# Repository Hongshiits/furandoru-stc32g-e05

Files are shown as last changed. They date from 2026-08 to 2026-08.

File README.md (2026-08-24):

# Furandoru STC32G E05

基于逐飞科技 `STC32G144K246 100Pin` 开源库和 Coreboard `E05_pwm_demo` 整理的 Furandoru 循迹车工程。仓库包含 E05 实际固件与修改后的 Coreboard 库、PC 端仿真、电路硬件安全导出，以及 SolidWorks/STEP/STL/DXF 等机械资料。

## 功能概览

- 五路 ADC 循迹信号采集与归一化（`LV / LH / MD / RH / RV`）
- 左右轮编码器反馈、PWM 电机驱动和增量式速度 PID
- IMU660RA 默认支持，可通过源码宏切换 IMU660RB
- 直线、弯道、十字和环岛等状态处理
- 串口 Horn Shell 参数调试，以及仍处于实验状态的 EEPROM 参数读写
- 双电机与虚拟导线循迹的纯 Python 仿真
- 立创 EDA/Altium 工程、BOM/Gerber、二维板框与按修改时间归档的安全导出
- SolidWorks 原生装配、可制造 STL/DXF/3MF 及带 GPL-3.0 许可证的轻量化车模快照

> 这是竞赛/实验固件快照。首次上车前请核对引脚、电机方向、传感器量程和 PID 参数，并先架空车轮测试。

> 本仓库不是逐飞科技官方仓库，当前按维护者要求保持公开。部分 Keil/STC、预编译 `.LIB`、硬件和机械资产随源目录未附独立再分发条款；公开可见不等于统一获得 GPL 授权。详见 [`THIRD_PARTY_NOTICES.md`](THIRD_PARTY_NOTICES.md)。

## 目录

```text
firmware/
├── E05_pwm_demo/
│   ├── code/       # Keil 工程保留的用户代码目录
│   ├── mdk/        # Keil C251 工程
│   └── user/       # Furandoru 应用代码
└── libraries/      # E05 工程引用的逐飞 Coreboard 库（含本项目修改）
tools/
└── e05_pwm_virtual_env/  # PC 端控制算法与导线循迹仿真
hardware/
├── projects/             # EDA 安全导出与 MUX_EMF 源工程
├── history/              # 按源修改时间整理的 EDA 历史版本
├── manufacturing/        # BOM、Gerber 与投板资料
├── libraries/            # 已审计的立创 EDA 元件库
└── mechanical-interfaces/ # 二维板框与接口图
mechanical/
├── solidworks/           # 原生模型、装配与制造格式
└── third-party/          # 保留上游许可证的第三方快照
scripts/
├── verify_project.py     # 固件工程相对路径检查
└── verify_assets.py      # 资产哈希、禁入格式与秘密标记检查
docs/
├── UPSTREAM_AND_CHANGES.md
├── ASSET_IMPORT_SUMMARY.md
└── ASSET_IMPORT_MAP.csv  # 原路径、时间、哈希、重命名/去重/排除追踪
```

## 克隆与 Git LFS

CAD/EDA/3D 二进制使用 Git LFS。完整克隆前先安装 Git LFS：

```powershell
git lfs install
git clone https://github.com/Hongshiits/furandoru-stc32g-e05.git
cd furandoru-stc32g-e05
git lfs pull
```

直接下载 GitHub 自动生成的源码 ZIP 时，LFS 文件可能只是指针；需要完整工程时应使用上述克隆方式。

## 构建固件

1. 安装支持 C251 的 Keil MDK 工具链和对应设备支持包。
2. 打开 [`firmware/E05_pwm_demo/mdk/seekfree.uvproj`](firmware/E05_pwm_demo/mdk/seekfree.uvproj)。
3. 确认目标设备为 `AI8052U-32Bit Series`，然后执行 Build。
4. 默认输出目录为 `firmware/E05_pwm_demo/mdk/out_file/`，输出名为 `SEEKFREE`。

工程使用相对路径 `../../libraries`，从仓库克隆后无需手工重连库文件。当前整理环境没有安装 Keil/C251，因此发布前完成的是工程引用完整性检查和 PC 仿真检查，而不是目标固件的实际编译。

## 关键配置入口

- ADC 通道：`firmware/E05_pwm_demo/user/adc.h`
- PWM、电机限幅与死区：`firmware/E05_pwm_demo/user/pwm.h`
- 编码器接口：`firmware/E05_pwm_demo/user/encoder.h`
- IMU 型号切换：`firmware/E05_pwm_demo/user/imu.h`
- 控制器初始参数：`firmware/E05_pwm_demo/user/algorithm.c`
- 赛道状态与阈值：`firmware/E05_pwm_demo/user/fsm_leg.c`

`user/ekf.*`、`user/gyro.*` 和 `user/matrix.*` 是当前保留的实验模块，尚未列入 `seekfree.uvproj` 的编译文件组。

当前源码中的主要默认连接如下：

| 功能 | 默认接口 |
| --- | --- |
| 五路循迹 ADC | `P06 / P03 / P02 / P01 / P00` |
| 电池电压 ADC | `P10` |
| 三路 PWM | `P74 / P24 / P70` |
| 电机方向 | `P35 / P36 / P37` |
| 左右编码器 | `P60/P62`、`P40/P42` |
| 调试串口 | UART5，`P05/P04`，115200 baud |
| 默认 IMU | IMU660RA；在 `imu.h` 中启用宏可切换 IMU660RB |
| 系统时钟 | 96 MHz |

EEPROM 相关源码仍带有“存在问题”的开发注释，应视为实验功能，在真机验证前不要依赖其保存关键参数。

## PC 仿真

工具仅依赖 Python 标准库；图形界面还需要 Python 自带的 Tk 支持。

```powershell
python tools/e05_pwm_virtual_env/e05_pwm_virtual_env.py --mode track --duration 8 --dt 0.01 --aim-speed 60 --direction 1
python tools/e05_pwm_virtual_env/e05_wire_graph_app.py --headless-steps 300
```

运行图形界面：

```powershell
python tools/e05_pwm_virtual_env/e05_wire_graph_app.py
```

## 发布前自检

```powershell
python scripts/verify_project.py
python scripts/verify_assets.py
```

第一个脚本验证 Keil 工程中的源文件和包含目录；第二个脚本核对 320 条资产导入记录、发布文件 SHA-256、禁入格式和常见秘密标记。

## 硬件与 3D 资产规则

硬件说明见 [`hardware/README.md`](hardware/README.md)，机械依赖与装配注意事项见 [`mechanical/README.md`](mechanical/README.md)。同名不同内容的独立文件使用 `__YYYYMMDD-HHMMSS` 后缀，字节相同的副本通常只保留一份；SolidWorks 装配体和依赖零件则保持原名同目录，避免破坏引用。唯一的跨上下文重复是 N30 主板支架 DXF：硬件接口目录保留一份，同时不破坏带许可证第三方快照的完整目录。

公开审计发现原始 `.eprj/.eprj2` 是带本地用户凭据的 SQLite 数据库，因此没有发布；可用工程以 `.epro/.epro2` 安全导出为准。147.9 MB 扫描参考图、构建日志、Keil 许可证码、调试/锁文件和来源未确认的商品图也已排除。完整原因和原始时间均在 [`docs/ASSET_IMPORT_MAP.csv`](docs/ASSET_IMPORT_MAP.csv)。

## 来源与许可证

本项目基于逐飞科技 STC32G144K 开源库，原文件版权声明均予以保留。整理基准、工作区修改范围和删减规则见 [`docs/UPSTREAM_AND_CHANGES.md`](docs/UPSTREAM_AND_CHANGES.md)。部分上游 C/汇编文件保留原始 GBK 或混合编码；整理过程没有批量转码，以免改变编译输入。

逐飞固件来源文件继续遵循其文件头声明的 GPLv3 或后续版本，项目自有修改也拟按 GPL-3.0-or-later 发布。根目录 [LICENSE](LICENSE) 收录 GPLv3 全文；`mechanical/third-party/lightweight-car-chassis/` 另保留其上游许可证。Keil、STC、预编译库及许可未明确的硬件/机械资产仍分别遵循其权利人的条款，仓库公开状态不改变这些第三方权利。

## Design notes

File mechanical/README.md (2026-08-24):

# 3D 模型与机械资料

本目录整理 SolidWorks 原生文件、制造/交换格式和一个带明确 GPL-3.0 许可证的逐飞轻量化车模快照。原始路径、修改时间、去重与排除记录见 [`docs/ASSET_IMPORT_MAP.csv`](../docs/ASSET_IMPORT_MAP.csv)。

## 目录

```text
mechanical/
├── solidworks/
│   ├── n30-zfcar/          # 原生装配/零件与 STL、DXF、3MF 导出
│   ├── custom-0429-130/    # Furandoru 自制零件、工程图与导出
│   └── fan-motor-mount/    # 负压风扇及电机支架
└── third-party/
    └── lightweight-car-chassis/ # SeekFree 项目及原 LICENSE/README
```

## SolidWorks 依赖保护

`solidworks/n30-zfcar/native/` 中所有 `.SLDASM` 和 `.SLDPRT` 保持原始文件名并置于同一目录，避免直接改名破坏装配引用：

| 装配体 | 依赖零件 |
| --- | --- |
| `Assem1.SLDASM` | `电磁支架固定2.SLDPRT`、`Mirror电磁支架固定2.SLDPRT` |
| `Assem2.SLDASM` | `电磁支架固定2.SLDPRT`、`Mirror电磁支架固定21.SLDPRT` |
| `Assem3.SLDASM` | `电磁支架固定2.SLDPRT`、`Mirror电磁支架固定2.SLDPRT` |

两个镜像零件还带有对原零件或装配上下文的外部引用。后续若要改名，请使用 SolidWorks **Pack and Go** 或“替换引用”，不要在资源管理器中直接改名。

`custom-0429-130/native/` 内的 `furan-fan-frame.SLDDRW`、`一体板板框_兼容逐飞_V1.1.SLDDRW` 和 `furan_top_support_rightMirror.SLDPRT` 保存过失效的旧绝对路径；其目标零件仍与它们同目录，SolidWorks 通常可通过同目录搜索恢复。首次打开后应人工确认所有引用，再另存或 Pack and Go。

## 版本与删减

- STL 和独立零件的同名不同内容版本使用 `__YYYYMMDD-HHMMSS` 后缀；字节完全相同的副本只保留一份。
- 原生装配依赖文件不参与文件系统重命名。
- 已排除 5 个 `~$` 锁文件、12 个 `.bak`、两个与解压内容完全相同的 ZIP、5 张许可未确认的商品参考图，以及一份二进制属性嵌入本地用户名且无法无损清理的 DWG。
- 发布的 DXF 已清除 `$LASTSAVEDBY` 和绝对源文件路径字段，几何实体保持不变。
- 已排除 `Scan2026-03-13_234830.png`（147,900,842 bytes，9637×13747）：它不是 3D 工程文件且超过 GitHub 普通 Git 的 100 MiB 单文件限制。

## 来源与许可

`third-party/lightweight-car-chassis/` 对应 SeekFree 的 Lightweight Car Chassis 项目，完整保留上游 `LICENSE`、中英文 README 和目录结构；其中后续加入的本地派生文件也按 GPL-3.0 兼容方式发布。

`n30-zfcar`、`fan-motor-mount` 以及 `custom-0429-130` 中带“逐飞”名称的部分在源目录中没有随附独立许可证，不能仅凭另一个目录含 GPL 文件就推定授权。它们按维护者的公开发布要求隔离整理，但公开可见本身不授予额外权利；复用或再分发前请核实来源和许可。详见 [`THIRD_PARTY_NOTICES.md`](../THIRD_PARTY_NOTICES.md)。

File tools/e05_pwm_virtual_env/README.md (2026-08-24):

# E05 PWM Virtual Environment

This folder provides a PC-side simulation for `firmware/E05_pwm_demo`.

## What is simulated

- `pt_pwm_init()` channel configuration
- `Motor_act()` direction + PWM absolute duty behavior
- Incremental motor PID logic from `pid_leg.c`
- A lightweight virtual plant for left/right encoder speed and yaw

The simulator is for algorithm validation and tuning trend checks. It is not intended to replace real hardware calibration.

## Run

From repository root:

```powershell
python tools/e05_pwm_virtual_env/e05_pwm_virtual_env.py --mode track --duration 8 --dt 0.01 --aim-speed 60 --direction 1
```

Corner-like mode:

```powershell
python tools/e05_pwm_virtual_env/e05_pwm_virtual_env.py --mode corner --duration 8
```

## Output

- Console summary with average PWM and final speeds/yaw
- CSV trace file (default): `tools/e05_pwm_virtual_env/sim_trace.csv`

You can change CSV output path:

```powershell
python tools/e05_pwm_virtual_env/e05_pwm_virtual_env.py --csv tools/e05_pwm_virtual_env/my_trace.csv
```

## Main parameters

- `--mode`: `track` or `corner`
- `--duration`: total simulation time in seconds
- `--dt`: simulation step period in seconds
- `--aim-speed`: equivalent to firmware `aim_speed`
- `--direction`: 1 (counterclockwise) or 2 (clockwise)

## Graph Simulation Application (Wire Signal Following)

The file `tools/e05_pwm_virtual_env/e05_wire_graph_app.py` is a graphical app for the E05 car scenario:

- A curved virtual wire radiates signal into air
- The car captures signal strength through 5 virtual sensors (`LV/LH/MD/RH/RV`)
- Steering uses an `Error_Turn` style formula similar to `isr_leg.c`
- Live graphs show ADC strength, error/yaw rate, and left/right PWM

Run GUI:

```powershell
python tools/e05_pwm_virtual_env/e05_wire_graph_app.py
```

Run headless quick check:

```powershell
python tools/e05_pwm_virtual_env/e05_wire_graph_app.py --headless-steps 300
```

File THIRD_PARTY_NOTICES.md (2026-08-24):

# 第三方组件与公开仓库说明

本仓库当前为公开仓库。本文件记录整理时能从源文件直接确认的许可证，以及仍未在源目录中找到独立再分发条款的组件。公开可见不等于这些组件统一改授仓库根目录的 GPL，也不替代权利人的正式许可。

## 逐飞 STC32G144K 固件库

`firmware/libraries` 和 E05 示例的大部分源文件包含成都逐飞科技有限公司的版权声明，并声明按 GPLv3 或后续版本授权。仓库根目录 `LICENSE` 保留了源工作副本提供的 GPLv3 全文；原文件头不得删除。

源文件头提到的 `libraries/doc/GPL3_permission_statement.txt` 和 `libraries/LICENSE` 在被整理的源工作副本中并不存在，只有仓库根目录 `LICENSE`。这里记录该不一致，不伪造缺失的上游文件。

## SeekFree Lightweight Car Chassis

`mechanical/third-party/lightweight-car-chassis/` 对应 SeekFree 的 Lightweight Car Chassis 项目，保留了上游 `LICENSE`、`README.md`、`README.en.md` 和原目录结构。该快照随附 GNU GPL v3；本地新增或派生的 `电磁支架底座.*`、DWG/DXF/SLDDRW 等文件按兼容方式公开，并由导入清单记录原修改时间。

上游来源：<https://gitee.com/seekfree/Lightweight_Car_Chassis>

## Keil、STC 与预编译库

以下固件构建依赖随源工作副本没有附带可单独确认的再分发条款：

- `firmware/libraries/zf_common/START251.A51`（Keil 版权声明）
- `firmware/libraries/zf_common/stc32g144k246.h`
- `firmware/libraries/zf_common/ai_usb.h`
- `firmware/libraries/zf_components/stc32g_usb_lib/`
- `firmware/libraries/zf_device/zf_device_config.LIB`
- `firmware/libraries/zf_device/zf_device_mt9v03x_dma.LIB`

它们为保持当前 Keil/C251 工程完整性而保留。维护者将仓库设为公开并不构成对其授权状态的保证；下游应核实 Keil、STC 或对应权利人的许可，或在分发前以已安装工具链/许可明确实现替换。

## 电路硬件资料

`hardware/` 中的 EDA 导出、制造文件和机械接口来自项目工作目录。以下类别在源目录中没有找到独立许可证，不能推定均适用根目录 GPL：

- 部分参考板 PDF（原 Altium 库因嵌入绝对用户路径且许可未明而未发布）
- 芯片数据手册及厂商文档
- MiniFOC、MUX_EMF 参考设计/代码
- 其他带厂商或第三方来源标识的工程

文件名明确为“仿逐飞1比1”的工程因授权未确认而未发布。原始 `.eprj/.eprj2/.eprj_backup` 因嵌入本地用户凭据而全部排除；只发布已审计的 `.epro/.epro2` 导出。含 Keil `LIC` 的构建日志和聚合 ZIP 也未进入仓库。具体结果见 `docs/ASSET_IMPORT_MAP.csv`。

## 其他 SolidWorks 模型

下列目录的源工作副本没有随附独立许可证：

- `mechanical/solidworks/n30-zfcar/`
- `mechanical/solidworks/fan-motor-mount/`
- `mechanical/solidworks/custom-0429-130/` 中带“逐飞”名称的部分

它们按维护者要求隔离整理并保持工程依赖，但不能仅因 SeekFree 的另一个项目带 GPL 文件就推定获得相同授权。复用、修改或再分发前应确认原作者、来源和适用条款。电商商品图及来源未确认的参考图没有发布。

## 安全与隐私删减

公开导入明确排除了：本地 EDA 凭据数据库、Keil 许可证码、绝对用户构建路径、调试日志、构建产物、个人状态文件、SolidWorks/Office 锁文件和 Office 作者元数据；DXF 头中的绝对源路径也已清除。`scripts/verify_assets.py` 会检查导入清单、哈希、禁入格式和常见秘密标记。

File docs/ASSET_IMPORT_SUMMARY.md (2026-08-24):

# 硬件与机械资产导入摘要

本摘要由本地导入脚本根据源文件 SHA-256、原始修改时间和工程依赖规则生成。Git 本身不保存文件修改时间，完整追溯信息见 [`ASSET_IMPORT_MAP.csv`](ASSET_IMPORT_MAP.csv)。

## 结果

- 源文件：320 个，403,850,217 bytes
- 实际发布：188 个，70,524,253 bytes
- 字节级去重：27 个源路径
- 排除：105 个源文件
- 同名不同内容版本组：12 组

## 同名不同内容的版本化结果

| 统一名称 | 版本 | 发布路径 | 原修改时间 | SHA-256 前 12 位 |
| --- | ---: | --- | --- | --- |
| `AI8052U-64-furan-0203.zip` | 1/5 | `hardware/history/easyeda/AI8052U-64-furan-0203/AI8052U-64-furan-0203__20260207-164544.zip` | 2026-02-07T16:45:44+08:00 | `BDD78105EEAB` |
| `↳` | 2/5 | `hardware/history/easyeda/AI8052U-64-furan-0203/AI8052U-64-furan-0203__20260207-184545.zip` | 2026-02-07T18:45:45+08:00 | `3B76DF684E0E` |
| `↳` | 3/5 | `hardware/history/easyeda/AI8052U-64-furan-0203/AI8052U-64-furan-0203__20260208-191833.zip` | 2026-02-08T19:18:33+08:00 | `5D4A5C32AF92` |
| `↳` | 4/5 | `hardware/history/easyeda/AI8052U-64-furan-0203/AI8052U-64-furan-0203__20260208-201833.zip` | 2026-02-08T20:18:33+08:00 | `460EB6462E17` |
| `↳` | 5/5 | `hardware/history/easyeda/AI8052U-64-furan-0203/AI8052U-64-furan-0203__20260208-211836.zip` | 2026-02-08T21:18:36+08:00 | `695D77CDF1BD` |
| `AI8052U-64-furan-0209 (1).epro2` | 1/2 | `hardware/history/easyeda/AI8052U-64-furan-0209 (1)/AI8052U-64-furan-0209 (1)__20260508-173740.epro2` | 2026-05-08T17:37:40+08:00 | `57D7F42667CC` |
| `↳` | 2/2 | `hardware/history/easyeda/AI8052U-64-furan-0209 (1)/AI8052U-64-furan-0209 (1)__20260508-223744.epro2` | 2026-05-08T22:37:44+08:00 | `467EE6108F1A` |
| `AI8052U-64-furan-0322.epro2` | 1/6 | `hardware/history/easyeda/AI8052U-64-furan-0322/AI8052U-64-furan-0322__20260521-224928.epro2` | 2026-05-21T22:49:28+08:00 | `74D4713A2D7C` |
| `↳` | 2/6 | `hardware/history/easyeda/AI8052U-64-furan-0322/AI8052U-64-furan-0322__20260521-234932.epro2` | 2026-05-21T23:49:32+08:00 | `B19FD54C1875` |
| `↳` | 3/6 | `hardware/history/easyeda/AI8052U-64-furan-0322/AI8052U-64-furan-0322__20260522-004935.epro2` | 2026-05-22T00:49:35+08:00 | `5C9283C3F653` |
| `↳` | 4/6 | `hardware/history/easyeda/AI8052U-64-furan-0322/AI8052U-64-furan-0322__20260522-014930.epro2` | 2026-05-22T01:49:30+08:00 | `AA692DF5E637` |
| `↳` | 5/6 | `hardware/history/easyeda/AI8052U-64-furan-0322/AI8052U-64-furan-0322__20260522-034932.epro2` | 2026-05-22T03:49:32+08:00 | `93A4187882EE` |
| `↳` | 6/6 | `hardware/history/easyeda/AI8052U-64-furan-0322/AI8052U-64-furan-0322__20260526-033540.epro2` | 2026-05-26T03:35:40+08:00 | `D8914A096168` |
| `AI8052U-64-furan-0322.zip` | 1/4 | `hardware/history/easyeda/AI8052U-64-furan-0322/AI8052U-64-furan-0322__20260501-184017.zip` | 2026-05-01T18:40:17+08:00 | `5D12ED271146` |
| `↳` | 2/4 | `hardware/history/easyeda/AI8052U-64-furan-0322/AI8052U-64-furan-0322__20260501-234021.zip` | 2026-05-01T23:40:21+08:00 | `3927154737BA` |
| `↳` | 3/4 | `hardware/history/easyeda/AI8052U-64-furan-0322/AI8052U-64-furan-0322__20260502-154026.zip` | 2026-05-02T15:40:26+08:00 | `25DC717CC795` |
| `↳` | 4/4 | `hardware/history/easyeda/AI8052U-64-furan-0322/AI8052U-64-furan-0322__20260502-174027.zip` | 2026-05-02T17:40:27+08:00 | `01D64096DE60` |
| `AI8052U-64-furan.zip` | 1/3 | `hardware/history/easyeda/AI8052U-64-furan/AI8052U-64-furan__20260203-015855.zip` | 2026-02-03T01:58:55+08:00 | `9D976504245E` |
| `↳` | 2/3 | `hardware/history/easyeda/AI8052U-64-furan/AI8052U-64-furan__20260203-155901.zip` | 2026-02-03T15:59:01+08:00 | `C0EBB80D1C19` |
| `↳` | 3/3 | `hardware/history/easyeda/AI8052U-64-furan/AI8052U-64-furan__20260203-185903.zip` | 2026-02-03T18:59:03+08:00 | `37A34C11C771` |
| `AI8052U-64核心板pt.zip` | 1/2 | `hardware/history/easyeda/AI8052U-64核心板pt/AI8052U-64核心板pt__20260207-153944.zip` | 2026-02-07T15:39:44+08:00 | `190163DAC64A` |
| `↳` | 2/2 | `hardware/history/easyeda/AI8052U-64核心板pt/AI8052U-64核心板pt__20260207-223949.zip` | 2026-02-07T22:39:49+08:00 | `ABBE293B33A6` |
| `逐飞负压风扇-pt.STL` | 1/2 | `mechanical/solidworks/custom-0429-130/exports/stl/逐飞负压风扇-pt__20260225-190454.STL` | 2026-02-25T19:04:54+08:00 | `33D8B070B1B6` |
| `↳` | 2/2 | `mechanical/solidworks/custom-0429-130/exports/stl/逐飞负压风扇-pt__20260319-191654.STL` | 2026-03-19T19:16:54+08:00 | `32BE0C7EAB7D` |
| `逐飞负压风扇.STL` | 1/2 | `mechanical/solidworks/custom-0429-130/exports/stl/逐飞负压风扇__20260202-200205.STL` | 2026-02-02T20:02:05+08:00 | `37A88BE0165E` |
| `↳` | 2/2 | `mechanical/solidworks/custom-0429-130/exports/stl/逐飞负压风扇__20260203-022557.STL` | 2026-02-03T02:25:57+08:00 | `7B1ACA32A0A8` |
| `逐飞负压风扇-pt.SLDPRT` | 1/2 | `mechanical/solidworks/custom-0429-130/native/逐飞负压风扇-pt__20260225-190421.SLDPRT` | 2026-02-25T19:04:21+08:00 | `6F632167571F` |
| `↳` | 2/2 | `mechanical/solidworks/custom-0429-130/native/逐飞负压风扇-pt__20260319-191328.SLDPRT` | 2026-03-19T19:13:28+08:00 | `C95A4EF28625` |
| `逐飞负压风扇.SLDPRT` | 1/2 | `mechanical/solidworks/custom-0429-130/native/逐飞负压风扇__20260202-195802.SLDPRT` | 2026-02-02T19:58:02+08:00 | `1E30681602C8` |
| `↳` | 2/2 | `mechanical/solidworks/custom-0429-130/native/逐飞负压风扇__20260203-022519.SLDPRT` | 2026-02-03T02:25:19+08:00 | `9CAB0C1F2292` |
| `支架固定1.STL` | 1/2 | `mechanical/solidworks/n30-zfcar/exports/stl/支架固定1__20260421-140613.STL` | 2026-04-21T14:06:13+08:00 | `99CAD6E41C96` |
| `↳` | 2/2 | `mechanical/solidworks/n30-zfcar/exports/stl/支架固定1__20260712-161544.STL` | 2026-07-12T16:15:44+08:00 | `B5DC1A7A3ACC` |
| `电磁支架固定2.STL` | 1/2 | `mechanical/solidworks/n30-zfcar/exports/stl/电磁支架固定2__20260421-134742.STL` | 2026-04-21T13:47:42+08:00 | `313A37FA6CD5` |
| `↳` | 2/2 | `mechanical/solidworks/n30-zfcar/exports/stl/电磁支架固定2__20260421-194806.STL` | 2026-04-21T19:48:06+08:00 | `E4C6564396AD` |

## 排除规则

| 原因 | 文件数 | 字节数 |
| --- | ---: | ---: |
| Altium 库嵌有本地绝对用户路径且未附独立再分发许可 | 4 | 6,124,032 |
| 147.9 MB 扫描参考图，不是 3D 工程且超过普通 Git 单文件限制 | 1 | 147,900,842 |
| CAD 自动备份；当前设计文件已单独保留 | 12 | 580,844 |
| DWG 二进制属性嵌有本地用户名，无法在无损验证下安全清除 | 1 | 49,465 |
| Keil 生成目录 | 30 | 5,122,542 |
| Keil 用户状态文件 | 4 | 201,358 |
| SolidWorks/Office 锁文件 | 5 | 30 |
| 原始立创 EDA SQLite 本地库含用户凭据；公开仓库仅接收重新导出的 .epro/.epro2 | 22 | 94,769,152 |
| 参考图片来源与再分发许可未确认，不属于电路工程 | 1 | 1,773,851 |
| 商品/建模参考图片来源与再分发许可未确认，不属于 3D 工程 | 5 | 926,146 |
| 容器元数据不同但展开内容与较新版本相同 | 2 | 1,846,222 |
| 已解压 DXF 制作文件的重复归档 | 1 | 34,859 |
| 已解压库的重复归档 | 4 | 9,673,157 |
| 已解压第三方项目的重复归档 | 1 | 526,558 |
| 已解压项目集合的重复归档 | 2 | 42,346,056 |
| 文件名表明是第三方 1:1 仿制工程，公开再分发授权未确认 | 2 | 2,804,562 |
| 调试日志 | 2 | 3,242,593 |
| 非制造交付的归档包不进入公开源码树；其解压内容或安全导出已单独整理 | 4 | 8,949,408 |
| 非必需的本地工具配置 | 2 | 76,066 |

## 依赖保护

- `mechanical/solidworks/n30-zfcar/native/` 内的 SolidWorks 装配体和零件保持原始文件名并置于同一目录，避免破坏装配引用。
- MUX_EMF 只保留 Keil 工程、配置和源码；`Objects/`、`Listings/` 及用户状态文件不发布。
- 原始 `.eprj/.eprj2` 是含本地用户凭据的 SQLite 数据库，全部排除；可发布工程仅使用已审计的 `.epro/.epro2` 导出。
- 完全相同的副本通常不重复存储；清单仍记录每个原路径、修改时间和哈希。N30 主板支架 DXF 是唯一跨上下文例外，用于同时保持硬件接口入口与完整第三方快照。
- DXF 的 `$LASTSAVEDBY` 和绝对源文件路径字段已从发布副本清除，几何实体保持不变。
- 147.9 MB 的扫描参考 PNG 不属于 3D 工程，且超过 GitHub 普通 Git 单文件限制，因此仅在清单留档。

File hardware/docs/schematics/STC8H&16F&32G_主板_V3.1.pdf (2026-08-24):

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
STC8H&16F&32G主板 | 路飞
| V3.1.0.0
2025/1/21 | 14:29:41
Title: | Author:

Date:

Revision:
Size: A4 | Time: | Sheet: | of:

### Subtitle: Revision

V2.2.0.0
更换舵机电源芯片、5V电源芯片为SP1N28STER；

# 版本号 修订日期 修订记录

2022-11-29

在此文件中，仅以版本号前两位(发行版)，划分版本之间的区别。

版权所有，保留一切权利。
本公司致力于产品的不断改善和功能升级，内容如有改动，恕不另行通知。

删除CCD1、2接口，有来有去接口；
增加2个无刷电调接口，1个TOF接口；
修改蜂鸣器信号引脚；

最高支持24V电源供电；

无线模块-串口增加CMD/(RST)信号引脚。

V2.3.0.0 | 2023-11-21 | 增加2个CCD接口。
V3.0.0.0 | 2024-01-08 | 增加3.3V电源，电源使能控制电路。
V3.0.1.0 | 2024-01-17 | RST复位引脚加上拉电阻。
V3.1.0.0 | 2025-01-16 | 修改编码器接口为GH125-6P，LED位号。

D D

C C

B B

A A

2 5

STC8H&16F&32G主板 | 路飞 V3.1.0.0
Title: | Author:
| Revision:

### Subtitle: BlockDiagram

### 7.2-24V DC IN

### 5V 稳压

### VBAT

### 电池输入

### 电机电源接口 端子X2

### 姿态传感器

### 编码器X2

屏幕

### 无线模块-串口

### SPI/IIC

### QTIMER

### SPI

### SCT2450

STC8H&16F&32G 运放 | ADCX4

### UART

电压测量 | ADC

### ToF接口

### 无刷电调接口X2

### IIC

PWM | 有刷电机接口 按键、拨码开关

### 蜂鸣器 GPIO

5V

### 1X3排针

### 2X3排针

图例：
双向信号： | 输出信号： | 输入信号： | 电源：

### 舵机稳压 SCT2450

舵机接口 | PWM

# 核心板

3.43V~8.31V

### 磁铁感应 GPIO

### 串口接口 UART

### CCD接口X2 GPIO

### ADC

### PWM

SY6280
5V

### 3.3V稳压

### 电子开关

RT9013-33

### 3.3V稳压

RT9013-33

3V3

3V3

### RST

### GPIO

D D

C C

B B

A A

3 5

STC8H&16F&32G主板 | 路飞 V3.1.0.0
Title: | Author:
| Revision:

### Subtitle: MCU

GND 1
VCC 2
GND 3
5.2 4
1.1 5
5.3 6
1.3 7
UCAP 8
6.1 9
6.0 10
6.3 11
6.2 12
4.4 13
1.4 14
1.6 15
1.5 16
5.4 17
1.7 18
4.0 19
4.7 20
6.5 21
6.4 22
6.7 23
6.6 24
3.7 | 33 3.6 34 7.0 | 35 4.1 36 7.2 | 37 7.1 38 2.0 | 39 7.3 40 2.1 | 41 4.2 42 2.3 | 43 2.2 44 2.5 | 45 2.4 46 2.7 | 47 2.6 48

4.5 64
4.6 63

3.1 25
3.0 26
3.3 27
3.2 28
3.5 29
3.4 30
5.1 31
5.0 32
0.1 | 49 0.0 50 7.4 | 51 0.2 52 7.6 | 53 7.5 54 4.3 | 55 7.7 56 0.4 | 57 0.3 58 0.6 | 59 0.5 60 1.0 | 61 0.7 62

U1

STC32G12K128_CoreBoard

# OLED TFT

# SCK MOSI RST

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
# MOSI MISO

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
# RTS

电机

# PWM PWM PWM PWM

按键

IO
IO
IO

# 外设 功能 对应引脚 SCK 4.0

# 外设 功能 对应引脚

运放

# 引脚表

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
# 编码器

# LSB

DIR | 3.5
| 3.4
| 0.4
| 5.3
ADC ADC ADC ADC | 0.0
| 0.1
| 0.5
| 0.6

2.7

0.7

IO

7.0
7.1
7.3

7.2

# LSB DIR

开关

# 电池电压 ADC 1.5 舵机 PWM

# 串口 Tx

Rx

1.1
1.0

7.4
XS

# SCL SDA

4.7

磁铁 IO | 2.6
| 6.5
| 6.3

0.3
0.2

GND

VCC5V

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
# PWM 3.3 PWM 7.7

# ToF

感应

# 蜂鸣器 IO 6.7

# CMD 4.5

# INT 4.4

姿态

# 传感器

1.3

1.4

3.6
3.7

# CCD

# ADC ADC

1.3
1.4
SI

# CLK

3.6
3.7

D D

C C

B B

A A

4 5

STC8H&16F&32G主板 | 路飞
| V3.1.0.0
2025/1/21 | 14:29:42
Title: | Author:
| Revision:

### Subtitle: PWR

1206
35V
X5R

4.7uF

C9

0603
50V
X7R

100nF

C10

200K

R8

0603 50V X7R

C11 100nF
5A 4.7uH

L2

1206
25V
X5R

47uF

C12 | 51K R9

10K

R11

10K

R12

LED2 20K R13

0603 50V X7R

C14 4.7nF

GND

SS54

D2

SS54

D3 VCC5V

1.5K

R10

VCCBAT

# 5V电源

G

SD

Q1
HY19P03

10K

R1

D1
BZT52C16 | 2
3

1

S1

GND

GND

VCCBAT

## 此电路为解决开关打火损耗而设计，可以用普通开关代替

电源接口/开关 | 1

2

DCOUT1

VCCBAT

GND | 1
2

DCOUT2

VCCBAT
GND

# 电机电源接口

1206
35V
X5R

4.7uF

C2

0603
50V
X7R

100nF

C3

200K

R2

0603 50V X7R

C4 100nF
5A 4.7uH

L1

1206
25V
X5R

47uF

C5 | 27K R3

8.2K

R5

10K

R6

LED1 20K R7

0603 50V X7R

C7 4.7nF

GND

VCCServo

VCCBAT

# 舵机电源

50K

R4

35V
100uF

C1

35V
100uF

C8

## 理论可调范围：3.43V~8.31V

Header-D-M 1x3P 1

2

3

P1

1K

R14 7.4
VCCServo

GND

BOOT 1
VIN 2
EN 3
RT/CLK 4 | FB 5

COMP 6

GND 7

SW 8 EP/GND

0

U2 SCT2450

BOOT 1
VIN 2
EN 3
RT/CLK 4 | FB 5

COMP 6

GND 7

SW 8 EP/GND

0

U3 SCT2450

IN 1
GND 2
EN 3 | NC 4

OUT 5

U4 RT9013-33

RST

VCC5V | VCC3V3

GND

IN 1
GND 2
EN 3 | NC 4

OUT 5

U5 RT9013-33

RST

VCC5V | VCCOP

GND

VOUT 1
GND 2
ISET 3
EN | 4
VIN | 5

U6 SY6280

0603
50V
X7R

100nF

C20

VCC5V_EXT | VCC5V
| RST

4.7K

R40

GND

4.7K R37

LED3

LED4

4.7K R38

10K

R39

LED5

0603
16V
X5R

10uF

C16

0603
16V
X5R

10uF

C17

0603
16V
X5R

10uF

C18

0603
16V
X5R

10uF

C19

T1

3V3

3V3

# 5V外设电源控制

25V

220uF

C6

25V

220uF

C13

1

2

P16 ⁽P1)

XT60_Header

D D

C C

B B

A A

5 5

STC8H&16F&32G主板 | 路飞
| V3.1.0.0
2025/1/21 | 14:29:42
Title: | Author:
| Revision:

### Subtitle: Device

Header-D-M 1x6P

1

2

3

4

5

6

P2

OUT1 | 7
VCC | 8
GND | 9
OUT2 | 10 OUT3 | 11 OUT4 | 12 IN4 1
GND 2
IN3 3
IN2 4
GND 5
IN1 6
OPA_MOD1
Header-D-M 2x3P ¹ 2
3 4
5 6

P13

Header-D-M 1x6P 1

2

3

4

5

6

P4

Header-D-F 1x8P 1

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
Header-D-M 1x4P

1
2
3
4

P7

Header-D-M 1x3P

1
2
3

P5

Header-D-M 1x3P

1
2
3

P6

Header-D-M 1x3P

1

2

3

P11

Header-D-M 1x6P 1

2

3

4

5

6

P12

Header-D-F 2x4P

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
VCCOP 0.0

0.1

0.5

0.6

200K

R15

20K

R16

0603 50V X7R

C15 100nF

VCCBAT

| GND

1.5

GND
VCC3V3 | 100R R¹⁷ ¹00R R¹8 2.5 2.3 2.0 2.1 2.2 2.7

VCC3V3

GND | 4.0 4.1 4.2 4.3

S4

S5

S6

R19 | 100R
R20 | 100R

RST

GND

R21 | 100R
R22 | 100R
R23 | 100R
R24 | 100R
R25 | 100R

7.0

7.1

7.2

7.3

7.5
7.6

RST

R26 | 10R
R27 | 4.7K
R28 | 10K

+

B1
BEEP

S8050

Q2

GND

VCC3V3

6.7

100R

R29
100R

R30

100R

R31
100R

R32

GND

GND

6.0 6.2

6.4 6.6

VCC5V_EXT

GND | 1.0
| 1.1
GND | GND

VCC5V_EXT

0.2

0.3
0.7

GND

GND | GND

GND
VCC3V3 ³.5 3.4 | 5.3 0.4

# 电磁运放模块接口

# 电压测量

# 屏幕接口

# 姿态传感器接口

# 拨码开关/按键

# 电机信号接口

# ToF模块接口

串口接口 | 蜂鸣器

# 无线模块-串口

# 磁铁感应模块接口

# 编码器接口

# 无刷电调接口

100R

R34

10K

R33

VCC3V3

2.6

VCC5V_EXT

GND | 6.5 6.3 4.7 4.4

4.5

### 1.电磁运放模块是逐飞科技OPA4377运放模块插座， 在PCB上对应器件为两个1x6P直插排座。并不是运 放芯片！ 2.参赛选手自己画原理图时，可以将运放模块电路集 成在主板上；也可以自行制作运放模块，只在主板上 放模块接口。

100R

R35
100R
R36 3.3 | 7.7

M1

Header-D-F 2x4P

1 2
3 4
5 6
7 8

P14

Header-D-F 2x4P

1 2
3 4
5 6
7 8

P15

M2 | M3 | M4

# 安装孔

# CCD接口

VCC3V3 | VCC3V3 | VCC3V3 | VCC3V3
GND | 1.3 | 1.4

GND

GND

3.6

3.7 | 3.6 | 3.7
R41 | 27K VCC5V

GND

VCC3V3

GH1.25-6P NC

ZB/Dir AVCC GND

P8 | GH1.25-6P NC

ZB/Dir AVCC GND

P9

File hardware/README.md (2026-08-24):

# 电路硬件资料

本目录整理自 Furandoru 上级工作目录中的电路工程、制造文件、封装库和机械接口。源文件共用的原始修改时间采用 `Asia/Hong_Kong`（UTC+08:00）；Git 不保存修改时间，因此版本时间、原路径和 SHA-256 统一记录在 [`docs/ASSET_IMPORT_MAP.csv`](../docs/ASSET_IMPORT_MAP.csv)。

## 目录

```text
hardware/
├── projects/               # 可公开的 .epro/.epro2 工程及 MUX_EMF 源码
├── history/easyeda/        # 已审计的 EDA 导出/备份版本
├── manufacturing/         # BOM、Gerber、投板 PDF
├── libraries/             # 已审计的立创 EDA 元件库
├── mechanical-interfaces/ # 主板二维板框与接口图
└── docs/                   # 需求、原理图和参考文档
```

`.epro`/`.epro2` 用立创 EDA 专业版导入。原 Altium `.PcbLib/.SCHLIB` 因二进制内嵌本地绝对用户路径且未附独立再分发许可而没有发布。MUX_EMF 子工程保留了 Keil 工程与 `Sources`，未保留 `Objects`、`Listings`、用户状态及构建日志。

## 公开发布安全处理

源目录中的 22 个 `.eprj/.eprj2/.eprj_backup` 不是普通交换文件，而是带本地 `users` 数据的 SQLite 数据库，其中存在非空凭据字段。因此这些文件全部未发布；仓库只收录经审计未命中用户凭据或 Keil 许可证码的 `.epro/.epro2` 导出和备份包。

这会造成两个有意的版本缺口：

- `AI8052U-64-furan-0322` 的原始本地工程更新到 2026-06-10，但当前可公开的最新 `.epro2` 导出是 2026-05-26 03:35:40。
- 五路运放的四个原始本地数据库版本未发布；安全历史目录中保留了 2026-05-05 和 2026-07-16 的导出版本。

如需补齐，应在立创 EDA 中打开本地工程并重新导出 `.epro2`，审计后再提交；不要直接提交 `.eprj2`。

同时排除了：含 Keil `LIC` 的聚合压缩包和构建日志、`debug.log`、`.aic`、Keil 编译产物、来源不明参考图片，以及文件名明确为第三方 1:1 仿制但未附再分发许可的工程。Office BOM/文档副本已清除作者、最后修改者、公司等 OOXML 元数据，DXF 的 `$FILENAME` 绝对源路径也已改为中性名称。

## 版本与去重规则

- 同名但内容不同：`<原名>__YYYYMMDD-HHMMSS.<扩展名>`。
- 修改时间也相同且内容不同：再追加 SHA-256 前 8 位。
- 内容完全相同：通常只保留修改时间较新的语义路径，所有原路径仍写入导入清单。唯一例外是 N30 主板支架 DXF，同时保留硬件接口副本与完整第三方快照中的原位置。
- `n30主板支架.step.dxf` 实际为 ASCII DXF，发布时纠正为 `.dxf` 并附加修改时间；未将它误标为 STEP/3D 模型。

## 许可说明

这些资料来自同一项目工作目录，但并非都自动适用仓库根目录的 GPL。厂商 PDF、MiniFOC、MUX 参考代码等随源目录未附独立许可证。公开可见不代表获得额外使用或再分发授权；使用前请查看 [`THIRD_PARTY_NOTICES.md`](../THIRD_PARTY_NOTICES.md) 并核实相应权利人的条款。

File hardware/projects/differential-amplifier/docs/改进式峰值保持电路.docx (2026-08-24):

改进式峰值保持电路

最近有同学向我求助，想让我对他们的电磁传感模块进行微型化改进。以此契机，我顺便研究了一下电磁传感器部分的经典放大-检波电路，并且有了一些新的思路，特来向你分享，并且希望可以对其他的参赛同学有参考作用。

首先贴一下传统的电路：

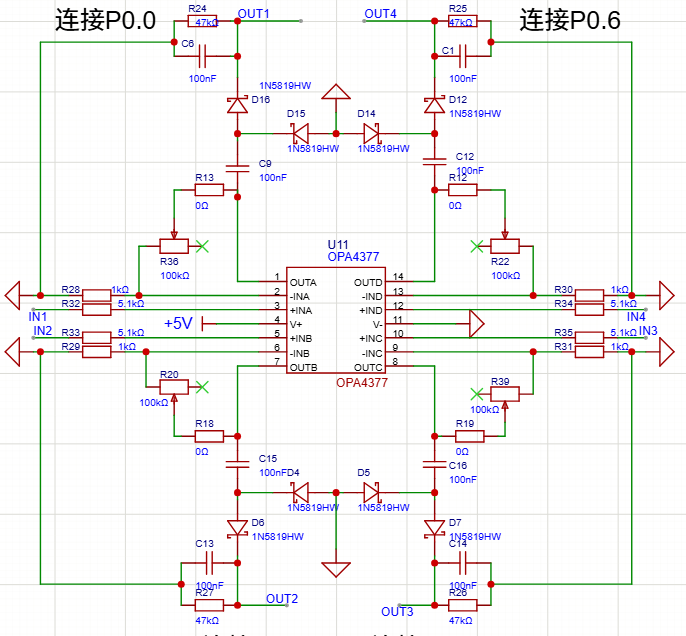
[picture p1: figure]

这个电路的原理就是，电磁信号经过LC谐振后，信号一端接地，一端经过运放进行可调的倍数放大（由100K的可调电阻控制倍数），然后放大后的信号，通过一个100nF电容隔离直流分量，再通过一个二极管进行检波，此时获得到的就是半波信号（负半周由另一个二极管对地泄放掉了），然后二极管因为单向导通的原理，所以电荷会积累在100nF的保持电容上，使其保持最大的电压峰值，这样就可以读到正弦波的峰值了，同时47K的电阻作为泄放电阻，用于缓慢泄放这个电荷，使其峰值下降的时候也能跟随。

我针对这种结构称作被动泄放方式，因为这里的泄放是不可控的，由47K电阻一直在泄放，这种方式下，当外部20Khz信号的峰峰值快速增大的时候，因为是二极管直接充电，所以跟随迅速，但是缺点也很明显，信号快速下降的时候，此时只能由47K电阻进行泄放。导致这个信号其实是有一个迟滞的，我管这个叫做“信号残影”。

针对这个问题，我对此做了一些小小的改动：

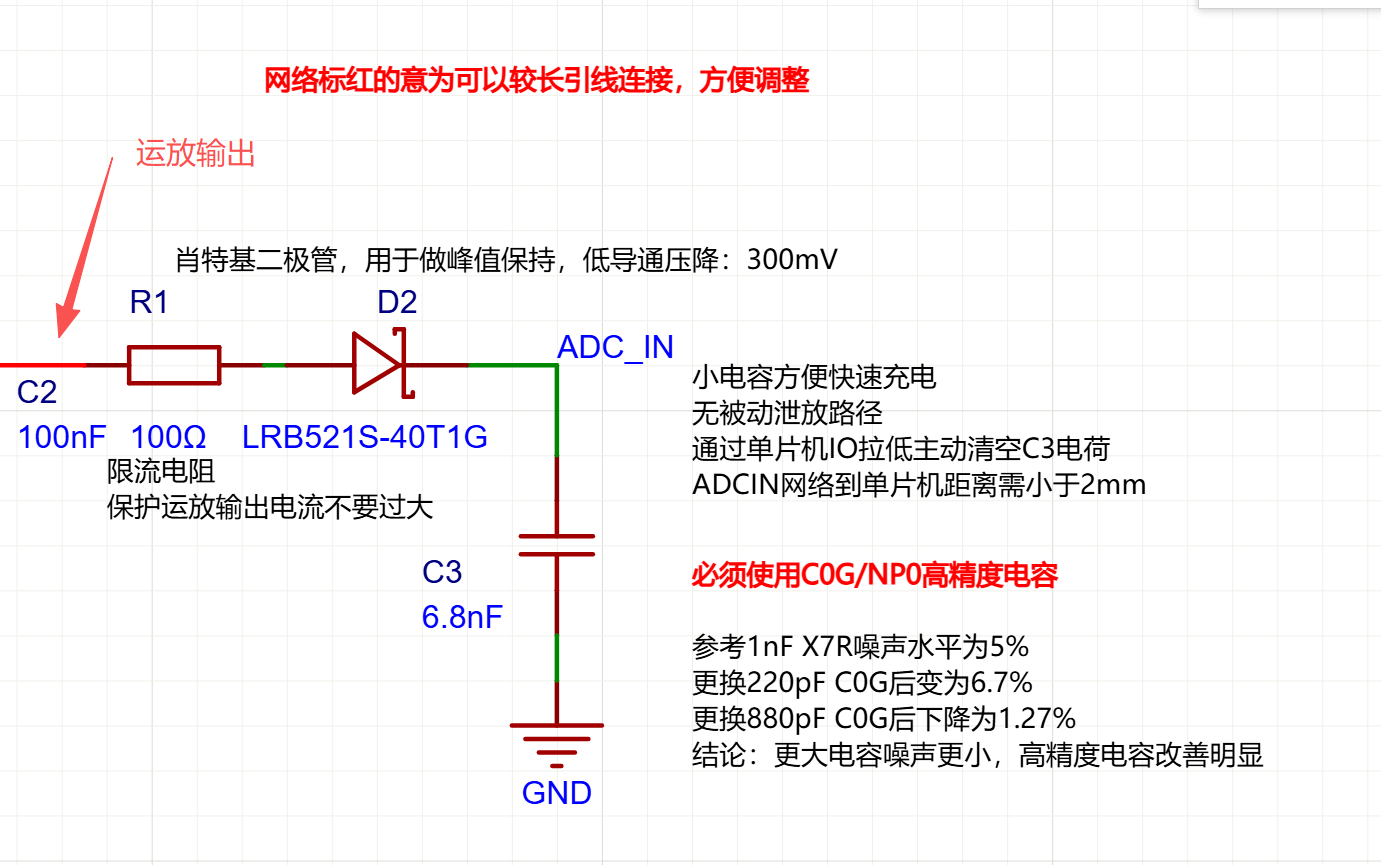
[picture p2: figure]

这张图中，我去除了被动泄放电阻，那么电荷从哪里走呢？我选择将单片机对应读取ADC的I/O口设置为开漏输出，这样输出1的时候单片机为高阻状态，可以读ADC，输出0的时候为强推挽到地，可以快速清空这个C3保持电容上的电荷。同时也巧妙利用的I/O的本身特性，无需额外驱动电路，仅靠软件控制I/O状态切换即可实现电荷的精准控制。

这里是有一个好处的，因为不清空的情况下，这个保持电容上的电荷无处泄放，所以会一直保持在一个很稳定的水平，具有很高的抗干扰和稳定性。且主动清空以后，电荷又是从0开始累计的，所以信号残影也被消除掉了。

这里我将肖特基二极管换成了一个更小压降的，这样可以更灵敏的探测低信号的电压。前面的100R电阻，主要的作用是防止I/O拉低的时候，因为和二极管形成通路，对运放的输出造成过大电流负担。从而保护运放输出级不被反向灌流损坏；而C3电容则改用低漏电的NP0材质，进一步抑制温漂与漏电流对峰值保持精度的影响。

同时，我还针对这个电路实际进行了打板测试，对应的结论也在图上，噪声水平与保持电容的大小和材质都呈正相关，使用NP0/C0G材质的电容可以非常明显的降低电路的噪声水平。

同时，之前的经典电路中使用了100nF的电容，我这里却只使用了6.8nF的电容，一个是NP0下不好找到那么大的电容，第二个是I/O口推挽下能走过的电流也有限，不能使用太大的电容对地放电，否则流过单片机的电流会过大，有概率损坏I/O口。

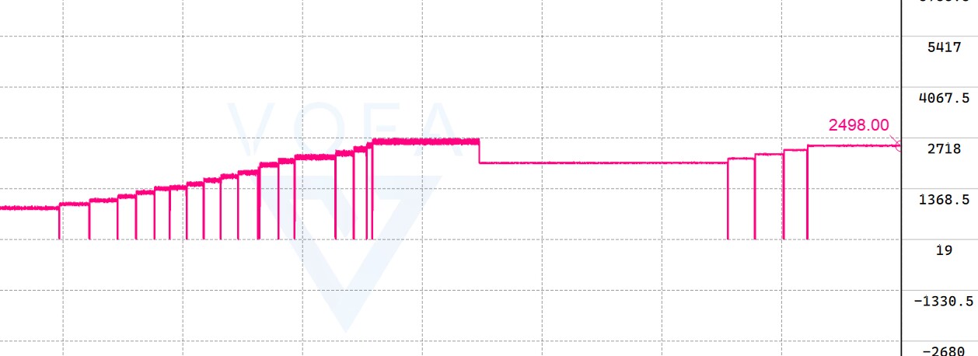
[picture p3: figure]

这里再贴一下我实际测试的图片，这个是由一个便携示波器产生的20Khz信号直接输入，然后调整这个信号的大小来进行捕获测试。

可以看到，这个示波器使用的其实是一个模拟开关来做的电压切换，因为其切换的时候可以明显读到0（全断开状态），这个也侧面证明了这个主动泄放方案的响应速度之迅速。

上图的左侧就是一个较小的NP0电容，右边是一个较大值的NP0电容，可以看到更大的电容明显具有更低的噪声水平

在880pF的NP0下，噪声水平就已经可以降低到1.27%了，且电路可以在2个电磁周期内进行峰值采样，响应十分迅捷。

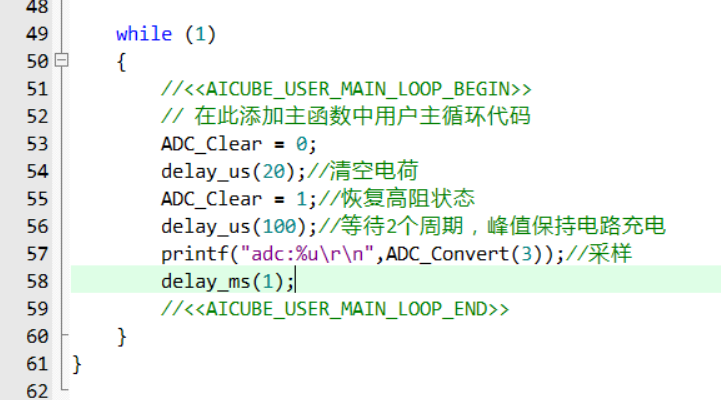
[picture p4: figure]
8f2c4c35493110b4d1a8d1e66c19ebe2

这里给出我的实际测试代码，ADC_Clear其实就是#define到了对应的IO口，拉低一段时间清空电荷，然后拉高并等待两个周期的峰值，再进行采样，既可以看到上面波形图中的读数了。

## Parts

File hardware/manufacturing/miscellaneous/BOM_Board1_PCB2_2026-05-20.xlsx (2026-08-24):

No. | Quantity | Comment | Designator | Footprint | Value | Manufacturer Part | Manufacturer | Supplier Part | Supplier | Category | Mounting Style | Device | Name
1 | 22 | 22uF | C1,C2,C3,C4,C5,C6,C7,C8,C9,C10,C11,C12,C13,C14,C15,C16,C17,C18,C19,C20,C24,C25 | C0805 | 22uF |  |  |  |  |  | SMT | CAP_0805 | 22uF
2 | 3 | 4.7uf | C21,C22,C23 | C0805 | 4.7uf |  |  |  |  |  | SMT | CAP_0805 | 4.7uf
3 | 5 | 100nF | C26,C28,C69,C70,C71 | C0402 | 100nF |  |  |  |  |  | SMT | CAP_0402 | 100nF
4 | 1 | 10uF | C27 | C0603 | 10uF |  |  |  |  |  | SMT | CAP_0603 | 10uF
5 | 1 | 22uF | C68 | C0603 | 22uF |  |  |  |  |  | SMT | CAP_0603 | 22uF
6 | 4 | B5819WS | D1,D2,D4,D20 | SOD-323_L1.7-W1.3-LS2.5-FD |  | B5819WS | R+O(宏嘉诚) | C7420331 | LCSC | 二极管:肖特基二极管 | SMT | B5819WS_C7420331 | B5819WS
7 | 1 | BZT52C15 | D3 | SOD-123_L2.7-W1.6-LS3.7-RD |  | BZT52C15 | R+O(宏嘉诚) | C19077412 | LCSC | 二极管:稳压二极管 | SMT | BZT52C15_C19077412 | BZT52C15
8 | 1 | DSK34 | D5 | SOD-123FL_L2.7-W1.8-LS3.8-RD |  | DSK34 | R+O(宏嘉诚) | C7502709 | LCSC | 二极管:肖特基二极管 | SMT | DSK34_C7502709 | DSK34
9 | 1 | HDR-M_2.54_1x3P | H8 | HDR-TH_3P-P2.54-V-M |  |  |  | C2937625 |  | 连接器:排针 | SMT | HDR-M_2.54_1x3P
10 | 1 | HDR-M_2.54_1x4P | H9 | HDR-TH_4P-P2.54-V-M |  |  |  | C492403 |  | 连接器:排针 | SMT | HDR-M_2.54_1x4P
11 | 1 | LED_0603-R | LED2 | LED_0603 |  |  |  |  |  |  | SMT | LED_0603-R
12 | 1 | LED_0603-G | LED4 | LED_0603 |  |  |  |  |  |  | SMT | LED_0603-G
13 | 5 | PAD | P1,P2,P3,P4,P5 | SMD_BD4.0-L4.0-W4.0-D1.0 |  | PAD |  | C9900017271 | LCSC |  | SMT | PAD | PAD
14 | 6 | TPN2R703NL,L1Q(ES) | Q1,Q2,Q3,Q4,Q5,Q6 | PDFN3333-8_L3.1-W3.2-P0.65-LS3.4-BL_1 |  | TPN2R703NL,L1Q(ES) | ElecSuper(静芯) | C49108772 | LCSC | 三极管/MOS管/晶体管:场效应管(MOSFET) | SMT | TPN2R703NL,L1Q(ES) | TPN2R703NL,L1Q(ES)
15 | 2 | 100R | R1,R41 | R0603 | 100R |  |  |  |  | 电阻:贴片电阻 | SMT | Res_0603 | 100R
16 | 6 | 4.7R | R2,R3,R4,R5,R6,R7 | R0603 | 4.7R |  |  |  |  | 电阻:贴片电阻 | SMT | Res_0603 | 4.7R
17 | 3 | 5.1K | R14,R16,R18 | R0603 | 5.1K |  |  |  |  | 电阻:贴片电阻 | SMT | Res_0603 | 5.1K
18 | 7 | 1K | R15,R17,R19,R20,R21,R22,R54 | R0603 | 1K |  |  |  |  | 电阻:贴片电阻 | SMT | Res_0603 | 1K
19 | 2 | 10K | R42,R44 | R0603 | 10K |  |  |  |  | 电阻:贴片电阻 | SMT | Res_0603 | 10K
20 | 1 | 47K | R43 | R0603 | 47K |  |  |  |  | 电阻:贴片电阻 | SMT | Res_0603 | 47K
21 | 1 | 4.7K | R55 | R0603 | 4.7K |  |  |  |  | 电阻:贴片电阻 | SMT | Res_0603 | 4.7K
22 | 1 | SE8650X2-HF | U11 | SOT-23-3_L2.9-W1.6-P1.90-LS2.8-BR |  | SE8650X2-HF | SEAWARD(思旺) | C496615 | LCSC | 电源管理:线性稳压器(LDO) | SMT | SE8650X2-HF | SE8650X2-HF
23 | 1 | FD6288Q | U12 | QFN-24_L4.0-W4.0-P0.50-BL-EP2.6 |  | FD6288Q | Fortior Tech(峰岹) | C328453 | LCSC | 电机驱动芯片:栅极驱动芯片 | SMT | FD6288Q | FD6288Q
24 | 1 | AI8051U-34K64-QFN48 | U13 | VQFN-48_L6.0-W6.0-P0.40-TL-EP4.1 |  | AI8051U-34K64-QFN48 | STC | C42388166 | LCSC | 单片机/微控制器:单片机(MCU/MPU/SOC) | SMT | AI8051U-34K64-QFN48 | AI8051U-34K64-QFN48

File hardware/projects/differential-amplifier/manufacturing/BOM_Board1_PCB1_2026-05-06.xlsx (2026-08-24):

No. | Quantity | Comment | Designator | Footprint | Value | Manufacturer Part | Manufacturer | Supplier Part | Supplier
1 | 1 | 100nF | C2 | C0402 | 100nF | CL05B104KO5NNNC | SAMSUNG(三星) | C1525 | LCSC
2 | 1 | 6.8nF | C3 | C0402 | 6.8nF | GRM1555C1H682GE01D | muRata(村田) | C3856821 | LCSC
3 | 1 | XH-4AW | CN1 | CONN-TH_XH-4AW |  | XH-4AW | HCTL(华灿天禄) | C2908613 | LCSC
4 | 1 | LRB521S-40T1G | D2 | SOD-523_L1.2-W0.8-LS1.6-RD |  | LRB521S-40T1G | LRC(乐山无线电) | C135802 | LCSC
5 | 4 | ZX-PZ1.27-1-2PZZ | H1,H2,H3,H4 | HDR-TH_2P-P1.27-V-M-2 |  | ZX-PZ1.27-1-2PZZ | Megastar(兆星) | C41370734 | LCSC
6 | 1 | 100Ω | R1 | R0402 | 100Ω | RC0402FR-07100RL | YAGEO(国巨) | C106232 | LCSC
7 | 1 | 5.1kΩ | R2 | R0402 | 5.1kΩ | RT0402BRD075K1L | YAGEO(国巨) | C852856 | LCSC
8 | 1 | 3kΩ | R3 | R0402 | 3kΩ | RT0402BRD073KL | YAGEO(国巨) | C281777 | LCSC
9 | 2 | 100kΩ | R4,R5 | R0402 | 100kΩ | RT0402BRD07100KL | YAGEO(国巨) | C852472 | LCSC
10 | 1 | 1kΩ | R6 | R0402 | 1kΩ | 0402WGF1001TCE | UNI-ROYAL(厚声) | C11702 | LCSC
11 | 1 | STC8H2K12U-45I-QFN20 | U1 | QFN-20_L3.0-W3.0-P0.40-TL-EP1.6 |  | STC8H2K12U-45I-QFN20 | STC | C42372297 | LCSC
12 | 3 | FSUSB42UMX-MS | U2,U4,U5 | UQFN-10_L1.8-W1.4-P0.40-TL |  | FSUSB42UMX-MS | MSKSEMI(美森科) | C50385399 | LCSC
13 | 1 | INA827AIDGKR | U3 | VSSOP-8_L3.0-W3.0-P0.65-LS5.0-BL |  | INA827AIDGKR | TI(德州仪器) | C2860185 | LCSC
14 | 1 | CJ431 | U6 | SOT-23-3_L2.9-W1.6-P1.90-LS2.8-BR |  | CJ431 | CJ(江苏长电/长晶) | C3113 | LCSC

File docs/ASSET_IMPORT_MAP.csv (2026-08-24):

source_tree | original_relative_path | action | repository_path | modified_local | size_bytes | sha256 | published_sha256 | note
hw | 246-48p_min/ProDoc_P1_2026-02-02.epro2 | included | hardware/projects/core-boards/246-48p-min/ProDoc_P1_2026-02-02.epro2 | 2026-02-02T06:28:47+08:00 | 125109 | AEF92D78C81E5BBCC4AEF7E7BA89472037CBDC0E73B4132ED30C9BD34260CB49 | AEF92D78C81E5BBCC4AEF7E7BA89472037CBDC0E73B4132ED30C9BD34260CB49 | 246-48p 最小系统工程
hw | 246-48p_min/ProDoc_PCB1_2026-02-02.epro2 | included | hardware/projects/core-boards/246-48p-min/ProDoc_PCB1_2026-02-02.epro2 | 2026-02-02T06:47:31+08:00 | 95905 | B5282C2F71840D75DCC645913FF8F854C16E2F2024AE861EEB1DF8A248D3346D | B5282C2F71840D75DCC645913FF8F854C16E2F2024AE861EEB1DF8A248D3346D | 246-48p 最小系统工程
hw | 5路运算放大器（OPA377+OPA4377).eprj2 | omitted |  | 2026-04-21T23:51:58+08:00 | 2641920 | 9F0CC95DBF5DD6769A286FDAF0B6200BE29973930CC4A2537671E770D04C81A3 |  | 原始立创 EDA SQLite 本地库含用户凭据；公开仓库仅接收重新导出的 .epro/.epro2
hw | AI8052U-48核心板-V1.0.eprj2 | omitted |  | 2026-02-02T03:40:15+08:00 | 5877760 | 5124F48407A7A58B58F3E69242A9723753A39D9CCB6AA501B113F6F1482BC203 |  | 原始立创 EDA SQLite 本地库含用户凭据；公开仓库仅接收重新导出的 .epro/.epro2
hw | AI8052U-64-furan-0203.eprj2 | omitted |  | 2026-02-09T18:01:40+08:00 | 7307264 | D87946E33A18B50B9DAB70B83596117007DCA89926341E352923C1609F37B24E |  | 原始立创 EDA SQLite 本地库含用户凭据；公开仓库仅接收重新导出的 .epro/.epro2
hw | AI8052U-64-furan-0203_backup/09a38df9580b46bf87e97675ddf3fe38/AI8052U-64-furan-0203_2026-02-07-16-45.zip | renamed | hardware/history/easyeda/AI8052U-64-furan-0203/AI8052U-64-furan-0203__20260207-164544.zip | 2026-02-07T16:45:44+08:00 | 1394319 | BDD78105EEABDB327CA408057901E672F258E38B8E32662EB54173A95AEDF7AE | BDD78105EEABDB327CA408057901E672F258E38B8E32662EB54173A95AEDF7AE | 已审计的 EDA 导出/备份；按源修改时间归档; 追加源文件修改时间
hw | AI8052U-64-furan-0203_backup/09a38df9580b46bf87e97675ddf3fe38/AI8052U-64-furan-0203_2026-02-07-18-45.zip | renamed | hardware/history/easyeda/AI8052U-64-furan-0203/AI8052U-64-furan-0203__20260207-184545.zip | 2026-02-07T18:45:45+08:00 | 1395149 | 3B76DF684E0E0BF0429F0F36A59EF9C04F3D324EB5C26E0AA71E160ACAC93B1D | 3B76DF684E0E0BF0429F0F36A59EF9C04F3D324EB5C26E0AA71E160ACAC93B1D | 已审计的 EDA 导出/备份；按源修改时间归档; 追加源文件修改时间
hw | AI8052U-64-furan-0203_backup/09a38df9580b46bf87e97675ddf3fe38/AI8052U-64-furan-0203_2026-02-08-19-18.zip | renamed | hardware/history/easyeda/AI8052U-64-furan-0203/AI8052U-64-furan-0203__20260208-191833.zip | 2026-02-08T19:18:33+08:00 | 1374724 | 5D4A5C32AF926F07DDB4B952D5543C0CA8E7FDFF3BFFEF4D0FDE7A424602C554 | 5D4A5C32AF926F07DDB4B952D5543C0CA8E7FDFF3BFFEF4D0FDE7A424602C554 | 已审计的 EDA 导出/备份；按源修改时间归档; 追加源文件修改时间
hw | AI8052U-64-furan-0203_backup/09a38df9580b46bf87e97675ddf3fe38/AI8052U-64-furan-0203_2026-02-08-20-18.zip | renamed | hardware/history/easyeda/AI8052U-64-furan-0203/AI8052U-64-furan-0203__20260208-201833.zip | 2026-02-08T20:18:33+08:00 | 1374872 | 460EB6462E177F0F8AF05FC1FF191EFA6841C35CA7E278C8F471FEA73DD2B861 | 460EB6462E177F0F8AF05FC1FF191EFA6841C35CA7E278C8F471FEA73DD2B861 | 已审计的 EDA 导出/备份；按源修改时间归档; 追加源文件修改时间
hw | AI8052U-64-furan-0203_backup/09a38df9580b46bf87e97675ddf3fe38/AI8052U-64-furan-0203_2026-02-08-21-18.zip | renamed | hardware/history/easyeda/AI8052U-64-furan-0203/AI8052U-64-furan-0203__20260208-211836.zip | 2026-02-08T21:18:36+08:00 | 1369646 | 695D77CDF1BD5251CC14A0FE95A9F1C106F12FF3A5B8F9B361846757AB09CADB | 695D77CDF1BD5251CC14A0FE95A9F1C106F12FF3A5B8F9B361846757AB09CADB | 已审计的 EDA 导出/备份；按源修改时间归档; 追加源文件修改时间
hw | AI8052U-64-furan-0209.eprj2 | omitted |  | 2026-03-16T21:52:05+08:00 | 7401472 | 322F8838D090CF8673EB764670E14269FC33E79B23FA2AD12C98464526C1AB57 |  | 原始立创 EDA SQLite 本地库含用户凭据；公开仓库仅接收重新导出的 .epro/.epro2
hw | AI8052U-64-furan-0322.eprj2 | omitted |  | 2026-04-06T16:07:03+08:00 | 9596928 | 75327C736DF8894ECA02096792B295343B3B33D00A14DE3B9A1A7729BDF68F96 |  | 原始立创 EDA SQLite 本地库含用户凭据；公开仓库仅接收重新导出的 .epro/.epro2
hw | AI8052U-64-furan.eprj2 | omitted |  | 2026-02-08T23:58:27+08:00 | 6643712 | 474D87BAECC1691D9512B044782E79510F859ACB5425DF8ACEB7623FEC202AC2 |  | 原始立创 EDA SQLite 本地库含用户凭据；公开仓库仅接收重新导出的 .epro/.epro2
hw | AI8052U-64-furan_backup/09a38df9580b46bf87e97675ddf3fe38/AI8052U-64-furan_2026-02-03-01-58.zip | renamed | hardware/history/easyeda/AI8052U-64-furan/AI8052U-64-furan__20260203-015855.zip | 2026-02-03T01:58:55+08:00 | 1352208 | 9D976504245E60882753C4C5BEA29713DD1EB5E7677B9376461F1E0B267EB812 | 9D976504245E60882753C4C5BEA29713DD1EB5E7677B9376461F1E0B267EB812 | 已审计的 EDA 导出/备份；按源修改时间归档; 追加源文件修改时间
hw | AI8052U-64-furan_backup/09a38df9580b46bf87e97675ddf3fe38/AI8052U-64-furan_2026-02-03-15-59.zip | renamed | hardware/history/easyeda/AI8052U-64-furan/AI8052U-64-furan__20260203-155901.zip | 2026-02-03T15:59:01+08:00 | 1377591 | C0EBB80D1C19F6E3EAB527B3F7FAF9D6B1DE694BDDC24CA9E457A4FB23B2C7A0 | C0EBB80D1C19F6E3EAB527B3F7FAF9D6B1DE694BDDC24CA9E457A4FB23B2C7A0 | 已审计的 EDA 导出/备份；按源修改时间归档; 追加源文件修改时间
hw | AI8052U-64-furan_backup/09a38df9580b46bf87e97675ddf3fe38/AI8052U-64-furan_2026-02-03-18-59.zip | renamed | hardware/history/easyeda/AI8052U-64-furan/AI8052U-64-furan__20260203-185903.zip | 2026-02-03T18:59:03+08:00 | 1347026 | 37A34C11C77189560794E04C3A66018875BC03B0552A6CF6EB1997D2D4C5C762 | 37A34C11C77189560794E04C3A66018875BC03B0552A6CF6EB1997D2D4C5C762 | 已审计的 EDA 导出/备份；按源修改时间归档; 追加源文件修改时间
hw | AI8052U-64核心板-V1.0.eprj2 | omitted |  | 2026-02-22T14:21:29+08:00 | 5840896 | 47B35F06FC294E20953A9D7B6EA30D6BF34902C37D6415E1C7CCD9DD98C15107 |  | 原始立创 EDA SQLite 本地库含用户凭据；公开仓库仅接收重新导出的 .epro/.epro2
hw | AI8052U-64核心板pt.eprj2 | omitted |  | 2026-03-02T02:10:39+08:00 | 6303744 | 5AD2A839639E8748EC33E2D17CE60D1DA5B727A9F214A8AF0B35381F4ACF24B1 |  | 原始立创 EDA SQLite 本地库含用户凭据；公开仓库仅接收重新导出的 .epro/.epro2
hw | AI8052U-64核心板pt_backup/09a38df9580b46bf87e97675ddf3fe38/AI8052U-64核心板pt_2026-02-07-15-39.zip | renamed | hardware/history/easyeda/AI8052U-64核心板pt/AI8052U-64核心板pt__20260207-153944.zip | 2026-02-07T15:39:44+08:00 | 1322369 | 190163DAC64A34EE92AAB314BC9E2C36A70819D54B39753976105D5D02601047 | 190163DAC64A34EE92AAB314BC9E2C36A70819D54B39753976105D5D02601047 | 已审计的 EDA 导出/备份；按源修改时间归档; 追加源文件修改时间
hw | AI8052U-64核心板pt_backup/09a38df9580b46bf87e97675ddf3fe38/AI8052U-64核心板pt_2026-02-07-18-39.zip | omitted |  | 2026-02-07T18:39:46+08:00 | 1322368 | 3B7C9DCF0B94753D64067922B4732C02C66BBAB245D78F15769173AE28A5D221 |  | 容器元数据不同但展开内容与较新版本相同
hw | AI8052U-64核心板pt_backup/09a38df9580b46bf87e97675ddf3fe38/AI8052U-64核心板pt_2026-02-07-22-39.zip | renamed | hardware/history/easyeda/AI8052U-64核心板pt/AI8052U-64核心板pt__20260207-223949.zip | 2026-02-07T22:39:49+08:00 | 1322368 | ABBE293B33A629A3B9A08EC3DDE6EBB96F9467FE96735AF138DEEF7203C57944 | ABBE293B33A629A3B9A08EC3DDE6EBB96F9467FE96735AF138DEEF7203C57944 | 已审计的 EDA 导出/备份；按源修改时间归档; 追加源文件修改时间
hw | bom/2BOM_Board1_Schematic1_2025-11-09.xlsx | included | hardware/manufacturing/legacy-bom/2BOM_Board1_Schematic1_2025-11-09.xlsx | 2025-11-09T16:22:19+08:00 | 12537 | E3F7A18842D9BDD19FBA1CD31B7017DE1FDA89A3BF2CAA5036793F5D6ABB82FF | 1D190F36629BA192075D6CA4B3D719E9255C92D62D15ECD63BEEA145943751B1 | 历史 BOM; 已清除 OOXML 作者/最后修改者元数据
hw | bom/BOM_Board1_foc_PCB1_2025-11-02.xlsx | included | hardware/manufacturing/legacy-bom/BOM_Board1_foc_PCB1_2025-11-02.xlsx | 2025-11-07T01:16:22+08:00 | 9493 | CD82D8C8C2184D010AE8C74ADD710AA8AEBC2F1B2B52D196D5D840D405AEFEA2 | FB3C970DCD163C00F43AA736D2AABECCBBC7C5B208B193BF73944E78711EDFCC | 历史 BOM; 已清除 OOXML 作者/最后修改者元数据
hw | bom/BOM_Board1_PCB1_2025-11-07.xlsx | included | hardware/manufacturing/legacy-bom/BOM_Board1_PCB1_2025-11-07.xlsx | 2025-11-07T01:14:47+08:00 | 12584 | 49C2AFB1BD1D2E0FE0100467253AECE26EA1C575555B8E7CA1B4254A5CA523E9 | B068EA9916FB56489A626685B3F221B50DF9168AC49D8CAF8814AD5861CD89FB | 历史 BOM; 已清除 OOXML 作者/最后修改者元数据
hw | BOM_Board1_PCB2_2026-05-20.xlsx | included | hardware/manufacturing/miscellaneous/BOM_Board1_PCB2_2026-05-20.xlsx | 2026-05-20T00:19:37+08:00 | 9043 | A63488AC453416AFC64843A3BA0431630F6FDB35958E4E4055BFEBE940C21D27 | 64173B833D7B3CEB503313B55DCE4E1AAA254E6E5F8A73F7822CF3EAC038BC96 | 制造或投板资料; 已清除 OOXML 作者/最后修改者元数据
hw | debug.log | omitted |  | 2026-04-22T14:24:39+08:00 | 6813 | 62D828922BEDFE6B0F9A9091596657D91748A37783BF150541584AC69873DDBA |  | 调试日志
hw | fulandre-sensor.eprj2 | omitted |  | 2026-04-21T23:46:25+08:00 | 610304 | 86D8A72DA52667AF5BECA6293A377702CB097E01BDA0E1AB3F50B704E028F4C0 |  | 原始立创 EDA SQLite 本地库含用户凭据；公开仓库仅接收重新导出的 .epro/.epro2
hw | fulandre-sensor_backup/2aac7155399442578f179cd9f7507029/fulandre-sensor_2026-04-12-17-06.zip | renamed | hardware/history/easyeda/fulandre-sensor/fulandre-sensor__20260412-170606.zip | 2026-04-12T17:06:06+08:00 | 62908 | 372FFA1862FAF0855A9E5A12D252512E85A677D200DA8EF5DCF07AE9907525C3 | 372FFA1862FAF0855A9E5A12D252512E85A677D200DA8EF5DCF07AE9907525C3 | 已审计的 EDA 导出/备份；按源修改时间归档; 追加源文件修改时间
hw | Gerber_PCB1_2025-10-27.zip | included | hardware/manufacturing/miscellaneous/Gerber_PCB1_2025-10-27.zip | 2025-10-27T23:47:57+08:00 | 276465 | 0D62AFF1FA7C982F3F788B5C9FB0264FDB46DEFCD8EF1AD2EAFF9885ED534C00 | 0D62AFF1FA7C982F3F788B5C9FB0264FDB46DEFCD8EF1AD2EAFF9885ED534C00 | 制造或投板资料
hw | lib/ProLib_1pcs_2026-02-02.elibz2 | included | hardware/libraries/easyeda/ProLib_1pcs_2026-02-02.elibz2 | 2026-02-02T05:57:11+08:00 | 2741 | 268DAF79C25066AF69D0DAAA701AA75AC45A14328CB677A46B5B3F7086A3BEFE | 268DAF79C25066AF69D0DAAA701AA75AC45A14328CB677A46B5B3F7086A3BEFE | 立创 EDA 元件库
hw | lib/ProLib_1pcs_2026-02-02R0402.elibz2 | included | hardware/libraries/easyeda/ProLib_1pcs_2026-02-02R0402.elibz2 | 2026-02-02T05:58:18+08:00 | 2885 | 524E8809590FA476DA899C1814ADEA2803A35839F3E65A01BA19B944BC856C4F | 524E8809590FA476DA899C1814ADEA2803A35839F3E65A01BA19B944BC856C4F | 立创 EDA 元件库
hw | minifoc/ProDoc_MiniFOC(N+P)_2026-04-26.epro2 | renamed | hardware/projects/motor-control/minifoc/ProDoc_MiniFOC(N+P)_2026-04-26__20260526-125629.epro2 | 2026-05-26T12:56:29+08:00 | 278396 | 0588227142B7468F99577D75115F77C1745AC4754E65EB1CB86212820105D2C1 | 0588227142B7468F99577D75115F77C1745AC4754E65EB1CB86212820105D2C1 | MiniFOC 工程资料; 追加源文件修改时间
hw | minifoc/SCH_原理图N+P_2026-04-26.pdf | included | hardware/projects/motor-control/minifoc/SCH_原理图N+P_2026-04-26.pdf | 2026-05-26T12:56:29+08:00 | 122471 | B30ECA2D04A5EE8479890BD404D1A4F81922FC19ABEC834A4F317C8DE38870BE | B30ECA2D04A5EE8479890BD404D1A4F81922FC19ABEC834A4F317C8DE38870BE | MiniFOC 工程资料
hw | minifoc/原理图及PCB(立创EDA专业版打开).zip | omitted |  | 2026-06-06T13:24:56+08:00 | 298699 | 3303269540214584AAB30AF4B077952533A7EE1C6FF977377F0CE4B0C1825AC8 |  | 非制造交付的归档包不进入公开源码树；其解压内容或安全导出已单独整理
hw | n30/5路运算放大器（OPA377+OPA4377).eprj2 | omitted |  | 2026-05-08T16:37:12+08:00 | 2641920 | CBE66BE3917C693B1D5E4A302035C8FFF62C9E5EA34F2D664FE0C83E0D5DC8EC |  | 原始立创 EDA SQLite 本地库含用户凭据；公开仓库仅接收重新导出的 .epro/.epro2
hw | n30/AI8052U-64-furan-0209 (1).eprj2 | omitted |  | 2026-05-08T17:37:42+08:00 | 11694080 | 8B7E18352E3F8759B09F9D6D5396B651EFF5F7FF844559E1366CD4D3FCA6282B |  | 原始立创 EDA SQLite 本地库含用户凭据；公开仓库仅接收重新导出的 .epro/.epro2
hw | n30/AI8052U-64-furan-0209 (1)_backup/AI8052U-64-furan-0209 (1)_2026-05-08-17-37.epro2 | renamed | hardware/history/easyeda/AI8052U-64-furan-0209 (1)/AI8052U-64-furan-0209 (1)__20260508-173740.epro2 | 2026-05-08T17:37:40+08:00 | 1981930 | 57D7F42667CC654768EE5780DAE5C99C55FD68D9D411766053F44AC40C19574E | 57D7F42667CC654768EE5780DAE5C99C55FD68D9D411766053F44AC40C19574E | 已审计的 EDA 导出/备份；按源修改时间归档; 追加源文件修改时间
hw | n30/AI8052U-64-furan-0209 (1)_backup/AI8052U-64-furan-0209 (1)_2026-05-08-22-37.epro2 | renamed | hardware/history/easyeda/AI8052U-64-furan-0209 (1)/AI8052U-64-furan-0209 (1)__20260508-223744.epro2 | 2026-05-08T22:37:44+08:00 | 1981947 | 467EE6108F1A0C4AFB4378960A459CCB1597A75310BD89AD72161F8676A6C2EE | 467EE6108F1A0C4AFB4378960A459CCB1597A75310BD89AD72161F8676A6C2EE | 已审计的 EDA 导出/备份；按源修改时间归档; 追加源文件修改时间
hw | n30/主板支架.dwg | renamed | hardware/mechanical-interfaces/n30/n30主板支架__20260508-173342.dwg | 2026-05-08T17:33:42+08:00 | 20736 | 5EE0383427995CEC50FF15CD40F0F14C0EBD360A29459826617653FD2CA19A2F | 5EE0383427995CEC50FF15CD40F0F14C0EBD360A29459826617653FD2CA19A2F | 主板机械接口；文件名记录源修改时间
hw | n30pro/5路运算放大器（OPA377+OPA4377).eprj2 | omitted |  | 2026-07-15T00:19:50+08:00 | 3092480 | 018A70D8E26D17FBF1955A842ACD77F4791C39084A95D2BDB6560BB5127A9648 |  | 原始立创 EDA SQLite 本地库含用户凭据；公开仓库仅接收重新导出的 .epro/.epro2
hw | n30pro/5路运算放大器（OPA377+OPA4377)_backup/5路运算放大器（OPA377+OPA4377)_2026-07-16-05-22.epro2 | renamed | hardware/history/easyeda/5路运算放大器（OPA377+OPA4377)/5路运算放大器（OPA377+OPA4377)__20260716-052206.epro2 | 2026-07-16T05:22:06+08:00 | 384070 | 0AE10B28ADB44D9633178A7FDF49D6381EA5817B218E3CDFEF15C1C4BBE468D9 | 0AE10B28ADB44D9633178A7FDF49D6381EA5817B218E3CDFEF15C1C4BBE468D9 | 已审计的 EDA 导出/备份；按源修改时间归档; 追加源文件修改时间
hw | n30pro/5路运算放大器（OPA377+OPA4377)_backup/671c48f351a041d8ae2680c8696138d0/5路运算放大器（OPA377+OPA4377)_2026-05-05-13-41.zip | renamed | hardware/history/easyeda/5路运算放大器（OPA377+OPA4377)/5路运算放大器（OPA377+OPA4377)__20260505-134102.zip | 2026-05-05T13:41:02+08:00 | 383633 | E306BD2640C3344A871278F84C03D63826FA99FCB97CC2649DD114184691FF9A | E306BD2640C3344A871278F84C03D63826FA99FCB97CC2649DD114184691FF9A | 已审计的 EDA 导出/备份；按源修改时间归档; 追加源文件修改时间
hw | n30pro/AI8052U-64-furan-0322.eprj2 | omitted |  | 2026-06-10T21:36:59+08:00 | 12390400 | 1BFCF8373DB4F3862F3928FAB71D27D1F4E2705DA9A6B08FDC81D89057E9961B |  | 原始立创 EDA SQLite 本地库含用户凭据；公开仓库仅接收重新导出的 .epro/.epro2
hw | n30pro/AI8052U-64-furan-0322_backup/09a38df9580b46bf87e97675ddf3fe38/AI8052U-64-furan-0322_2026-05-01-18-40.zip | renamed | hardware/history/easyeda/AI8052U-64-furan-0322/AI8052U-64-furan-0322__20260501-184017.zip | 2026-05-01T18:40:17+08:00 | 1873939 | 5D12ED2711460E2E776B61DC81D4E36D4182505754A3A3C746676239151E29C5 | 5D12ED2711460E2E776B61DC81D4E36D4182505754A3A3C746676239151E29C5 | 已审计的 EDA 导出/备份；按源修改时间归档; 追加源文件修改时间
hw | n30pro/AI8052U-64-furan-0322_backup/09a38df9580b46bf87e97675ddf3fe38/AI8052U-64-furan-0322_2026-05-01-23-40.zip | renamed | hardware/history/easyeda/AI8052U-64-furan-0322/AI8052U-64-furan-0322__20260501-234021.zip | 2026-05-01T23:40:21+08:00 | 1924606 | 3927154737BAEF5BC9E81A13680DD254A0470B16D5C0B59B3B2491D8505CF9FF | 3927154737BAEF5BC9E81A13680DD254A0470B16D5C0B59B3B2491D8505CF9FF | 已审计的 EDA 导出/备份；按源修改时间归档; 追加源文件修改时间
hw | n30pro/AI8052U-64-furan-0322_backup/09a38df9580b46bf87e97675ddf3fe38/AI8052U-64-furan-0322_2026-05-02-15-40.zip | renamed | hardware/history/easyeda/AI8052U-64-furan-0322/AI8052U-64-furan-0322__20260502-154026.zip | 2026-05-02T15:40:26+08:00 | 1934708 | 25DC717CC79507ABD63ABE653BB82D1780AF471E213E304E0A776BF5E89C1E72 | 25DC717CC79507ABD63ABE653BB82D1780AF471E213E304E0A776BF5E89C1E72 | 已审计的 EDA 导出/备份；按源修改时间归档; 追加源文件修改时间
hw | n30pro/AI8052U-64-furan-0322_backup/09a38df9580b46bf87e97675ddf3fe38/AI8052U-64-furan-0322_2026-05-02-17-40.zip | renamed | hardware/history/easyeda/AI8052U-64-furan-0322/AI8052U-64-furan-0322__20260502-174027.zip | 2026-05-02T17:40:27+08:00 | 1937836 | 01D64096DE60BAC34F1A841627D71731D5187424D37914EF98ED083A1D702A9A | 01D64096DE60BAC34F1A841627D71731D5187424D37914EF98ED083A1D702A9A | 已审计的 EDA 导出/备份；按源修改时间归档; 追加源文件修改时间
hw | n30pro/AI8052U-64-furan-0322_backup/AI8052U-64-furan-0322_2026-05-21-22-49.epro2 | renamed | hardware/history/easyeda/AI8052U-64-furan-0322/AI8052U-64-furan-0322__20260521-224928.epro2 | 2026-05-21T22:49:28+08:00 | 1955827 | 74D4713A2D7CB04352516A3A3C6FC47FB64A6910D4D35D051BEB074AEF61CCF7 | 74D4713A2D7CB04352516A3A3C6FC47FB64A6910D4D35D051BEB074AEF61CCF7 | 已审计的 EDA 导出/备份；按源修改时间归档; 追加源文件修改时间
hw | n30pro/AI8052U-64-furan-0322_backup/AI8052U-64-furan-0322_2026-05-21-23-49.epro2 | renamed | hardware/history/easyeda/AI8052U-64-furan-0322/AI8052U-64-furan-0322__20260521-234932.epro2 | 2026-05-21T23:49:32+08:00 | 1970675 | B19FD54C187589A77D2919AF8D16BF5E1A1CBCA896BF074F35EA81AE786F0568 | B19FD54C187589A77D2919AF8D16BF5E1A1CBCA896BF074F35EA81AE786F0568 | 已审计的 EDA 导出/备份；按源修改时间归档; 追加源文件修改时间
hw | n30pro/AI8052U-64-furan-0322_backup/AI8052U-64-furan-0322_2026-05-22-00-49.epro2 | renamed | hardware/history/easyeda/AI8052U-64-furan-0322/AI8052U-64-furan-0322__20260522-004935.epro2 | 2026-05-22T00:49:35+08:00 | 1974372 | 5C9283C3F653DD3B63C6081B11F4533F86C709307CF5AD9A2D65FE7CD5778C42 | 5C9283C3F653DD3B63C6081B11F4533F86C709307CF5AD9A2D65FE7CD5778C42 | 已审计的 EDA 导出/备份；按源修改时间归档; 追加源文件修改时间
hw | n30pro/AI8052U-64-furan-0322_backup/AI8052U-64-furan-0322_2026-05-22-01-49.epro2 | renamed | hardware/history/easyeda/AI8052U-64-furan-0322/AI8052U-64-furan-0322__20260522-014930.epro2 | 2026-05-22T01:49:30+08:00 | 2005936 | AA692DF5E63777742AADF718F6AA30717433F340F663140753B7D1D923C8CE5C | AA692DF5E63777742AADF718F6AA30717433F340F663140753B7D1D923C8CE5C | 已审计的 EDA 导出/备份；按源修改时间归档; 追加源文件修改时间
hw | n30pro/AI8052U-64-furan-0322_backup/AI8052U-64-furan-0322_2026-05-22-03-49.epro2 | renamed | hardware/history/easyeda/AI8052U-64-furan-0322/AI8052U-64-furan-0322__20260522-034932.epro2 | 2026-05-22T03:49:32+08:00 | 2011502 | 93A4187882EE670DC08FF6884E06507256D2B42E54D324111363E19DCC7501D1 | 93A4187882EE670DC08FF6884E06507256D2B42E54D324111363E19DCC7501D1 | 已审计的 EDA 导出/备份；按源修改时间归档; 追加源文件修改时间
hw | n30pro/AI8052U-64-furan-0322_backup/AI8052U-64-furan-0322_2026-05-26-03-35.epro2 | renamed | hardware/history/easyeda/AI8052U-64-furan-0322/AI8052U-64-furan-0322__20260526-033540.epro2 | 2026-05-26T03:35:40+08:00 | 2012907 | D8914A096168853CADEC41E13330B19F6CCA1EC2394566AE427B8A09B77C97DF | D8914A096168853CADEC41E13330B19F6CCA1EC2394566AE427B8A09B77C97DF | 已审计的 EDA 导出/备份；按源修改时间归档; 追加源文件修改时间
hw | n30pro/debug.log | omitted |  | 2026-07-21T07:54:43+08:00 | 3235780 | 21B3792B0C11329B14628FE3F86DD007211A471743A6D190C466BE89820B6C39 |  | 调试日志
hw | n30pro/n30pro.zip | omitted |  | 2026-06-10T22:31:38+08:00 | 30265471 | 29B0B6D7ABF46ACA47A5C3CFE96D53DCFD7C329458493038D5F96FB66BF3144C |  | 已解压项目集合的重复归档
hw | n30pro/n30主板支架.step.dxf | renamed | hardware/mechanical-interfaces/n30/n30主板支架__20260429-223911.dxf | 2026-04-29T22:39:11+08:00 | 163927 | A90EBF36BA882EE05EED80C3CBFACAA187B58C1E82CB7CF530E407E060C2A09E | B54AB7E9DB74F1746CC2F9B99C31971FC9B55F776B6EE8E3D3B73E4181E9D846 | 主板机械接口；文件名记录源修改时间; 追加源文件修改时间; 已清除 DXF $FILENAME 绝对源路径
hw | n30pro/ProDoc_MiniFOC(N+P)_2026-04-26.epro2 | deduplicated | hardware/projects/motor-control/minifoc/ProDoc_MiniFOC(N+P)_2026-04-26__20260526-125629.epro2 | 2026-05-26T12:56:29+08:00 | 278396 | 0588227142B7468F99577D75115F77C1745AC4754E65EB1CB86212820105D2C1 |  | 与 MiniFOC 发布文件展开内容相同，仅容器元数据不同
hw | n30pro/ProPrj_电磁挖孔仿逐飞1比1.epro2 | omitted |  | 2026-03-04T19:42:55+08:00 | 1402281 | 17FF3E0A71DAAEFA8BD679639D45E0AA1301E46CE6F3D017E98F26500CE90F8D |  | 文件名表明是第三方 1:1 仿制工程，公开再分发授权未确认
hw | PCB_0526-PCB2_2026-06-03.pdf | included | hardware/manufacturing/miscellaneous/PCB_0526-PCB2_2026-06-03.pdf | 2026-06-03T22:31:07+08:00 | 713237 | 6824C50A2191ABA1697613FD93F61778FE70D41F4D47137F765CD54307B393F8 | 6824C50A2191ABA1697613FD93F61778FE70D41F4D47137F765CD54307B393F8 | 制造或投板资料
hw | ProPrj_bmi270陀螺仪11_2026-03-13.epro2 | included | hardware/projects/sensors-and-analog/ProPrj_bmi270陀螺仪11_2026-03-13.epro2 | 2026-05-09T12:11:20+08:00 | 214852 | 79E151AA9CE46E7DF2111B9C406986CCF08986A2C25983E55FF32BBCAE02654D | 79E151AA9CE46E7DF2111B9C406986CCF08986A2C25983E55FF32BBCAE02654D | EDA 工程
hw | ProPrj_iot-furandoru-mainboard_2025-10-20.epro | included | hardware/projects/integration-and-power/ProPrj_iot-furandoru-mainboard_2025-10-20.epro | 2025-10-20T22:32:46+08:00 | 149154 | DEB747F2B0D156B6E131859FA28B7304BA1547DEDAAFFCF27E1DDDC1781B0E42 | DEB747F2B0D156B6E131859FA28B7304BA1547DEDAAFFCF27E1DDDC1781B0E42 | EDA 工程
hw | ProPrj_iot-furandoru-mainboard_2025-10-23.epro | included | hardware/projects/integration-and-power/ProPrj_iot-furandoru-mainboard_2025-10-23.epro | 2025-10-23T21:48:33+08:00 | 370149 | E08FAA247B5299A4A1C2EC982C454A758FE7020F383523B8132ED6B02D552F24 | E08FAA247B5299A4A1C2EC982C454A758FE7020F383523B8132ED6B02D552F24 | EDA 工程
hw | ProPrj_TPS54302的5V输出电路设计_2026-05-22.epro2 | included | hardware/projects/integration-and-power/ProPrj_TPS54302的5V输出电路设计_2026-05-22.epro2 | 2026-05-22T00:50:03+08:00 | 47142 | FCC7CD4E2FA9E1B30F3E20F5DDEFA902E725202DDEB721A677084E1C8507FA20 | FCC7CD4E2FA9E1B30F3E20F5DDEFA902E725202DDEB721A677084E1C8507FA20 | EDA 工程
hw | ProPrj_电磁挖孔仿逐飞1比1.epro2 | omitted |  | 2026-03-04T19:42:55+08:00 | 1402281 | 17FF3E0A71DAAEFA8BD679639D45E0AA1301E46CE6F3D017E98F26500CE90F8D |  | 文件名表明是第三方 1:1 仿制工程，公开再分发授权未确认
hw | SL27517.eprj2 | omitted |  | 2026-04-12T18:28:39+08:00 | 606208 | F5D64F8656332897DA2C95EAFD4FA07526C16FCA41CF9EB21DE6BCB571EECBDE |  | 原始立创 EDA SQLite 本地库含用户凭据；公开仓库仅接收重新导出的 .epro/.epro2
hw | SL27517_backup/3c63afe58be64a7998f3264b1b7f182a/SL27517_2026-04-12-21-28.zip | renamed | hardware/history/easyeda/SL27517/SL27517__20260412-212839.zip | 2026-04-12T21:28:39+08:00 | 95186 | 535BDCD7F92519AFB2BE698444427A1BEBA44091C39B6F4E3FF00324526D873D | 535BDCD7F92519AFB2BE698444427A1BEBA44091C39B6F4E3FF00324526D873D | 已审计的 EDA 导出/备份；按源修改时间归档; 追加源文件修改时间
hw | Slkor-SL27517.PDF | included | hardware/docs/datasheets/Slkor-SL27517.PDF | 2026-04-12T20:04:33+08:00 | 785465 | BBE68A20DFF0C7258B19C8311540525105BF27636E7D8589D4ED8C2CA24E3BA8 | BBE68A20DFF0C7258B19C8311540525105BF27636E7D8589D4ED8C2CA24E3BA8 | 硬件参考文档
hw | STC16F 主板V2.3 集成封装库.7z | omitted |  | 2025-10-22T20:33:10+08:00 | 2026817 | 85CFAAF86A3D3999ACA0308EA48C60E693AD07CF0CFE6C54D687C71F2C8085A8 |  | 已解压库的重复归档
hw | STC32G144K246主板V1.0原理图.pdf | included | hardware/docs/schematics/STC32G144K246主板V1.0原理图.pdf | 2026-02-03T02:44:56+08:00 | 410370 | 8C4011041FD350F154B18C1751E243DE403B67910DF95F437D8B7A2EE4FDA10D | 8C4011041FD350F154B18C1751E243DE403B67910DF95F437D8B7A2EE4FDA10D | 硬件参考文档
hw | STC32G_CoreBoard_V2.1.pdf | included | hardware/docs/schematics/STC32G_CoreBoard_V2.1.pdf | 2025-10-23T01:09:33+08:00 | 250396 | 8F35CDAA4CE3F9479653133E0F77842E4E3B8BFF9BDDD7E2B5D0CF3EA7BCAB4A | 8F35CDAA4CE3F9479653133E0F77842E4E3B8BFF9BDDD7E2B5D0CF3EA7BCAB4A | 硬件参考文档
hw | STC32G_缩微主板_V1.0 (1).pdf | included | hardware/docs/schematics/STC32G_缩微主板_V1.0 (1).pdf | 2026-04-12T20:03:49+08:00 | 340721 | BF75D227181495C9B4F4828530C207DA733392745B25EA6ADE4FA9A6A2B6EFCF | BF75D227181495C9B4F4828530C207DA733392745B25EA6ADE4FA9A6A2B6EFCF | 硬件参考文档
hw | STC8H&16F&32G_主板_V3.1.7z | omitted |  | 2025-10-22T20:34:02+08:00 | 2638026 | B7B23A527BBBC51241F95552F6B6E5140258BBB995B02FE4FF704E6624594CC6 |  | 已解压库的重复归档
hw | STC8H&16F&32G_主板_V3.1.pdf | included | hardware/docs/schematics/STC8H&16F&32G_主板_V3.1.pdf | 2025-10-22T20:26:57+08:00 | 6375004 | A3A9EE9DC7614BAD10FAF432EC119CB6148ED4E694ADF8148920BD618E5F0267 | A3A9EE9DC7614BAD10FAF432EC119CB6148ED4E694ADF8148920BD618E5F0267 | 硬件参考文档
hw | STC8H&16F&32G_主板_V3.1/STC8H&16F&32G_主板_V3.1.PcbLib | omitted |  | 2025-01-21T15:43:09+08:00 | 3091968 | F68E29C0BD9A4F9FF332F17F9292109E4AA0784C2B9461FCC9B11EE2A37E7AB9 |  | Altium 库嵌有本地绝对用户路径且未附独立再分发许可
hw | STC8H&16F&32G_主板_V3.1/STC8H&16F&32G_主板_V3.1.SCHLIB | omitted |  | 2025-01-21T15:43:46+08:00 | 303104 | ECABCD030B06C09ACB6D0EB3561CF891311432244A0C52770F069270D9C49FF6 |  | Altium 库嵌有本地绝对用户路径且未附独立再分发许可
hw | STC8H&16F&32G_主板_V3.1/STC8H&16F&32G_主板_V3.1.zip | omitted |  | 2025-10-22T20:38:03+08:00 | 2815614 | 143F3CE7BFE3182D52B3EE7D01C26763E756A23AF08BEA67CA42BD6E81BBAD34 |  | 已解压库的重复归档
hw | stc无刷电调.eprj2 | omitted |  | 2026-05-11T12:55:42+08:00 | 2269184 | FDBCEB583A7ADB2D2A0B20D8D4C0CB16220EFA325A66986DC179CCF7232DB913 |  | 原始立创 EDA SQLite 本地库含用户凭据；公开仓库仅接收重新导出的 .epro/.epro2
hw | stc无刷电调_backup/stc无刷电调_2026-05-11-22-25.epro2 | omitted |  | 2026-05-11T22:25:28+08:00 | 523854 | D7A8247480C371E0CF12449298548E4BB6E553775C580D05076E0F33EE4E7DE3 |  | 容器元数据不同但展开内容与较新版本相同
hw | stc无刷电调_backup/stc无刷电调_2026-05-12-03-25.epro2 | renamed | hardware/history/easyeda/stc无刷电调/stc无刷电调__20260512-032530.epro2 | 2026-05-12T03:25:30+08:00 | 523854 | A040FED468FF70E8947F711415AFCBE270035F4E3A377A5501584AA574A11543 | A040FED468FF70E8947F711415AFCBE270035F4E3A377A5501584AA574A11543 | 已审计的 EDA 导出/备份；按源修改时间归档; 追加源文件修改时间
hw | 【封装】STC16F 主板V2.3 集成封装库/STC8H&16F&32G_主板_V2.3.PcbLib | omitted |  | 2023-11-28T16:37:08+08:00 | 2444800 | B8ACDDE5A0DD39A395183230273D893C7E1EE0DCE20934CDCEFADDA8A7CD0DF2 |  | Altium 库嵌有本地绝对用户路径且未附独立再分发许可
hw | 【封装】STC16F 主板V2.3 集成封装库/STC8H&16F&32G_主板_V2.3.SCHLIB | omitted |  | 2023-11-28T16:36:43+08:00 | 284160 | 543BFA13CFA6456DBE55ADA32247059FA3E769B634EAAC054C4C932C858C7CB2 |  | Altium 库嵌有本地绝对用户路径且未附独立再分发许可
hw | 【封装】STC16F 主板V2.3 集成封装库/【封装】STC16F 主板V2.3 集成封装库.zip | omitted |  | 2025-10-22T20:34:43+08:00 | 2192700 | 9103BD378485FB244F3E38B2FD0A25495BFD0EB20273860BF01F7645CB844815 |  | 已解压库的重复归档
hw | 差分电磁放大/PCB下单文件/BOM_Board1_PCB1_2026-05-06.xlsx | included | hardware/projects/differential-amplifier/manufacturing/BOM_Board1_PCB1_2026-05-06.xlsx | 2026-05-26T02:57:50+08:00 | 7979 | D8B66827B6D4BD27F6840115BD82D4B5A3DF66528069B47EEAA94F75BBF8F16A | 56D48A4936C81477FD34F61BB5CAA5D5E74C16A83A43CCEFC342ED9FF40878EC | 差分放大板制造文件; 已清除 OOXML 作者/最后修改者元数据
hw | 差分电磁放大/PCB下单文件/Gerber_MUX_EMF_2026-05-06.zip | included | hardware/projects/differential-amplifier/manufacturing/Gerber_MUX_EMF_2026-05-06.zip | 2026-05-26T02:57:50+08:00 | 66973 | 3332204F76F11C571DD7A8E2E5D2F6D2444962F5F22F14C1EFAD092A52F34347 | 3332204F76F11C571DD7A8E2E5D2F6D2444962F5F22F14C1EFAD092A52F34347 | 差分放大板制造文件
hw | 差分电磁放大/PCB下单文件/PickAndPlace_PCB1_2026_05_06.xlsx | included | hardware/projects/differential-amplifier/manufacturing/PickAndPlace_PCB1_2026_05_06.xlsx | 2026-05-26T02:57:50+08:00 | 8554 | 9126B8722846C414FFE6C99CF6831C8C0E83938D70487E1EE57DCD72F0C31666 | 6022AF9F7960F69AB6248252D88B0FB24B8EC1336A8099231DCC410DD4A10673 | 差分放大板制造文件; 已清除 OOXML 作者/最后修改者元数据
hw | 差分电磁放大/差分电磁放大.zip | omitted |  | 2026-06-06T13:24:04+08:00 | 4176005 | CECA34F2157CA5CA6029003893EB200A590D2BEDE649D0BC7327C937B34FCBDB |  | 非制造交付的归档包不进入公开源码树；其解压内容或安全导出已单独整理
hw | 差分电磁放大/开源代码/MUX_EMF/Listings/adc.lst | omitted |  | 2026-05-26T02:57:49+08:00 | 4127 | B34F025ED1A5E65434506975714F8CEEA8DD5B3FD535F9C3A791A71F213B99E0 |  | Keil 生成目录
hw | 差分电磁放大/开源代码/MUX_EMF/Listings/clock.lst | omitted |  | 2026-05-26T02:57:49+08:00 | 3063 | E7B2272CBEAFFF01FCDBD961A76A6DD74B48D30055CD52DF619C17A24538FE8D |  | Keil 生成目录
hw | 差分电磁放大/开源代码/MUX_EMF/Listings/main.lst | omitted |  | 2026-05-26T02:57:49+08:00 | 9077 | AD7283DB6B6C7A60001330F791DA9E2309004E9199C16D2735E07CD468537801 |  | Keil 生成目录
hw | 差分电磁放大/开源代码/MUX_EMF/Listings/MUX_EMF.m51 | omitted |  | 2026-05-26T02:57:48+08:00 | 22943 | A278A8073D750C9F7BF2220846C4950227BCAF0A4918239752838907E75B723B |  | Keil 生成目录
hw | 差分电磁放大/开源代码/MUX_EMF/Listings/port.lst | omitted |  | 2026-05-26T02:57:48+08:00 | 4561 | 47534D6F12DFC515CC4832B3A8DC38CE676D8250AC896B57A9DA545310156A86 |  | Keil 生成目录
hw | 差分电磁放大/开源代码/MUX_EMF/Listings/uart.lst | omitted |  | 2026-05-26T02:57:48+08:00 | 8231 | 81F3B61270BD65311AE5AB9CCDDFA21DCFEE34AB1D3D5402FF5C606CAA6CB9E7 |  | Keil 生成目录
hw | 差分电磁放大/开源代码/MUX_EMF/MUX_EMF.aic | omitted |  | 2026-05-26T02:57:50+08:00 | 38033 | 5618AC38B35D835D9978C2EF0FD10EACBD45FA6AEEF06B5F0A4095AEC5E4D864 |  | 非必需的本地工具配置
hw | 差分电磁放大/开源代码/MUX_EMF/MUX_EMF.uvgui.王昱顺 | omitted |  | 2026-05-26T02:57:50+08:00 | 92888 | AAD9B994518B8C11A59EB1B5BE1DA11931ADCBB916776EF668EF7C6E44348479 |  | Keil 用户状态文件
hw | 差分电磁放大/开源代码/MUX_EMF/MUX_EMF.uvopt | omitted |  | 2026-05-26T02:57:49+08:00 | 7791 | FDA2A62A5311860122907573B32F7022ECF778B9D6FDFA79D975BE9DD6EF907C |  | Keil 用户状态文件
hw | 差分电磁放大/开源代码/MUX_EMF/MUX_EMF.uvproj | included | hardware/projects/differential-amplifier/firmware/MUX_EMF.uvproj | 2026-05-26T02:57:49+08:00 | 15075 | 287DC02E16AB5293C048B666AA8BAEFB50B1D4A4E801BE8D4AFC1ABE58A5C2AE | 287DC02E16AB5293C048B666AA8BAEFB50B1D4A4E801BE8D4AFC1ABE58A5C2AE | MUX_EMF 固件源码
hw | 差分电磁放大/开源代码/MUX_EMF/Objects/adc.obj | omitted |  | 2026-05-26T02:57:50+08:00 | 248212 | BB9207F5973C2760749964F5E456F7539F7EBC3DCEC25622095B5FF5A7997F0E |  | Keil 生成目录
hw | 差分电磁放大/开源代码/MUX_EMF/Objects/clock.obj | omitted |  | 2026-05-26T02:57:51+08:00 | 246926 | C8717918218B23BED95D18A308364E786F8D53C5525A206192EED71BB30FC2B8 |  | Keil 生成目录
hw | 差分电磁放大/开源代码/MUX_EMF/Objects/main.obj | omitted |  | 2026-05-26T02:57:51+08:00 | 255357 | 635F7DE21D343D104C4B59C4BA908ADA2D3BC8EFEBE5CFA0234921D1DD1E87B2 |  | Keil 生成目录
hw | 差分电磁放大/开源代码/MUX_EMF/Objects/MUX_EMF | omitted |  | 2026-05-26T02:57:50+08:00 | 1250722 | F163E570B90EC4DA034B1EA974201E5C8A261A9B0A5040D241C1F74FACD14B0D |  | Keil 生成目录
hw | 差分电磁放大/开源代码/MUX_EMF/Objects/MUX_EMF.build_log.htm | omitted |  | 2026-05-26T02:57:51+08:00 | 1021 | DF9D60EAA60CF6FA4F54236FD831DF76784AFDF972676865EF99687E711C0C92 |  | Keil 生成目录
hw | 差分电磁放大/开源代码/MUX_EMF/Objects/MUX_EMF.hex | omitted |  | 2026-05-26T02:57:51+08:00 | 6020 | CB6078DE76B637CD6D14393206E09E0FD51B7076054C8A63E411310840934807 |  | Keil 生成目录
hw | 差分电磁放大/开源代码/MUX_EMF/Objects/MUX_EMF.lnp | omitted |  | 2026-05-26T02:57:51+08:00 | 209 | F215E7229F4CD76086912C76CAE5D62AA570334FB33D34C7CF58C95748E26400 |  | Keil 生成目录
hw | 差分电磁放大/开源代码/MUX_EMF/Objects/port.obj | omitted |  | 2026-05-26T02:57:51+08:00 | 249048 | 0DA2307FD77C9831922044163F7D8141D63E24A649EECC0D893877924DE5E845 |  | Keil 生成目录
hw | 差分电磁放大/开源代码/MUX_EMF/Objects/uart.obj | omitted |  | 2026-05-26T02:57:51+08:00 | 251754 | 1AE596CA9422BD37C406FD3FA7346AD6B70D225C309537BE6E666ED261A4FD2B |  | Keil 生成目录
hw | 差分电磁放大/开源代码/MUX_EMF/Sources/adc.c | included | hardware/projects/differential-amplifier/firmware/Sources/adc.c | 2026-05-26T03:16:17+08:00 | 2326 | A02E81DE5E5B7C6131DA4F1EF8E2CDECBDD19A4BD7C4C98F259E8E04D9A7A986 | A02E81DE5E5B7C6131DA4F1EF8E2CDECBDD19A4BD7C4C98F259E8E04D9A7A986 | MUX_EMF 固件源码
hw | 差分电磁放大/开源代码/MUX_EMF/Sources/clock.c | included | hardware/projects/differential-amplifier/firmware/Sources/clock.c | 2026-05-26T03:15:12+08:00 | 1474 | 5FF95720D064DFBAFC22462C4899860B82C03E878A7C983801C0220B3BE7FC89 | 5FF95720D064DFBAFC22462C4899860B82C03E878A7C983801C0220B3BE7FC89 | MUX_EMF 固件源码
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

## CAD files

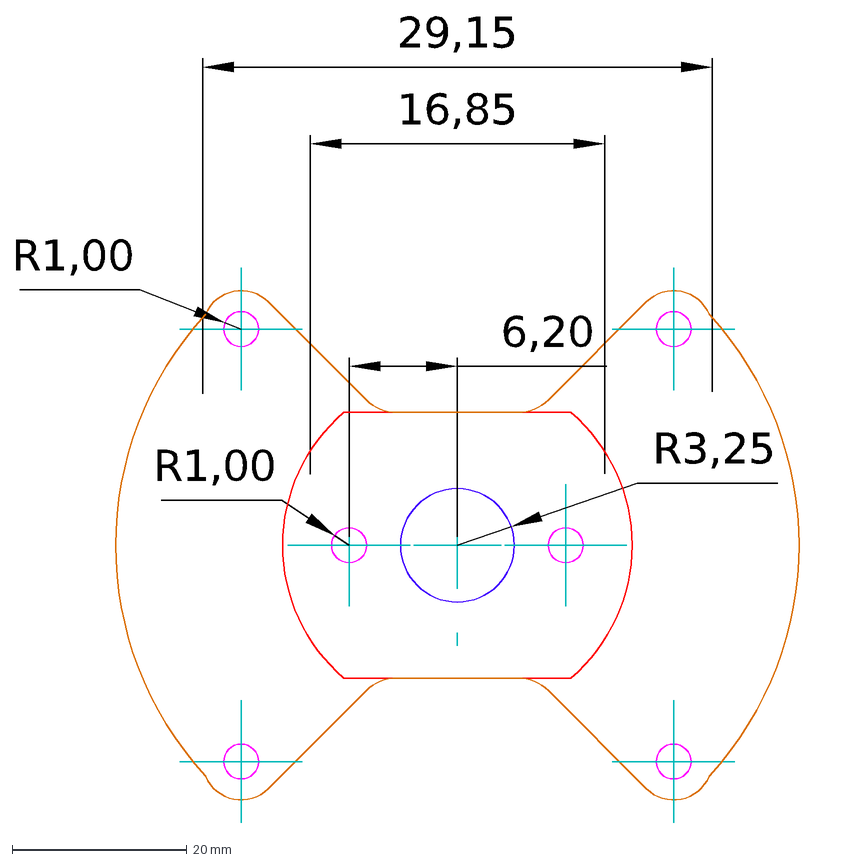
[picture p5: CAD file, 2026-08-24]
mechanical/solidworks/fan-motor-mount/exports/dxf/底板（逐飞）furan_fan_8701.dxf
R1,00
R3,25
16,85
6,20
29,15

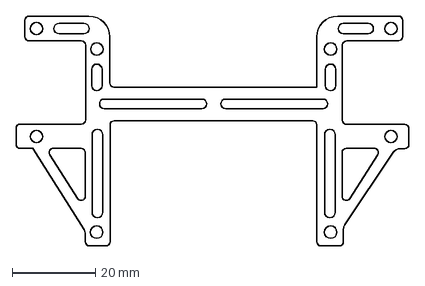
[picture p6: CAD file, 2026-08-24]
mechanical/solidworks/n30-zfcar/exports/dxf/主板支架.DXF
94.5 x 55.2 mm

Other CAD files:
mechanical/solidworks/n30-zfcar/native/Assem1.SLDASM
mechanical/solidworks/n30-zfcar/native/Assem2.SLDASM
mechanical/solidworks/n30-zfcar/native/Assem3.SLDASM
hardware/mechanical-interfaces/n30/n30主板支架__20260508-173342.dwg
mechanical/solidworks/custom-0429-130/exports/dxf/fulan_sensor0412.dxf
mechanical/solidworks/custom-0429-130/exports/step/test_Part1.STEP
mechanical/solidworks/custom-0429-130/exports/stl/fulan_support.STL
mechanical/solidworks/custom-0429-130/native/furan_car.dwg
mechanical/solidworks/fan-motor-mount/exports/stl/离心风机（逐飞—1.8mm）.STL
mechanical/solidworks/fan-motor-mount/native/底板（逐飞）.SLDPRT
mechanical/solidworks/n30-zfcar/exports/3mf/Mirror电磁支架固定2.3mf
mechanical/solidworks/n30-zfcar/exports/stl/主板底板.STL
mechanical/solidworks/n30-zfcar/native/方形螺母.SLDPRT
hardware/mechanical-interfaces/n30/n30主板支架__20260429-223911.dxf
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

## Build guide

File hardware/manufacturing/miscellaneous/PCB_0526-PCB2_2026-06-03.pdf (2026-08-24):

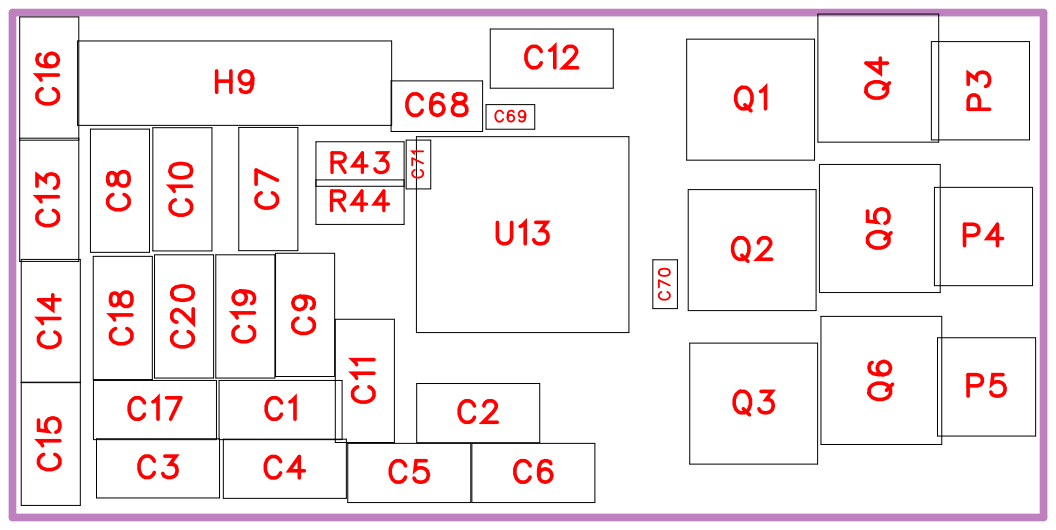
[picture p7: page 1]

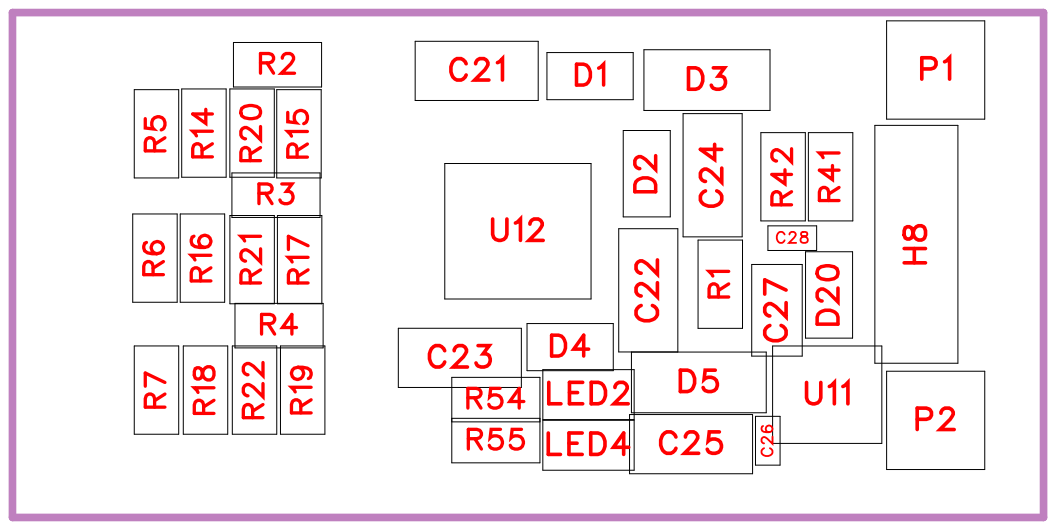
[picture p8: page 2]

R55 | LED4 | C25

No. | Quantity | Comment | Designator | Footprint | Value | Manufacturer Part | Manufacturer | Supplier Part | Supplier | Category | Mounting Style
1 | 22 | 22uF | C1,C2,C3,C4,C5,C6,C7,C8, C9,C10,C11,C12,C13,C14, C15,C16,C17,C18,C19,C20 ,C24,C25 | C0805 | 22uF | | | | | | SMT
2 | 3 | 4.7uf | C21,C22,C23 | C0805 | 4.7uf | | | | | | SMT
3 | 5 | 100nF | C26,C28,C69,C70,C71 | C0402 | 100nF | | | | | | SMT
4 | 1 | 10uF | C27 | C0603 | 10uF | | | | | | SMT
5 | 1 | 22uF | C68 | C0603 | 22uF | | | | | | SMT
6 | 4 | B5819WS | D1,D2,D4,D20 | SOD-323_L1 .7-W1.3-LS2. 5-FD | | B5819WS | R+O(宏嘉诚) | C7420331 | LCSC | 二极管:肖特 基二极管 | SMT
7 | 1 | BZT52C15 | D3 | SOD-123_L2 .7-W1.6-LS3. 7-RD | | BZT52C15 | R+O(宏嘉诚) | C19077412 | LCSC | 二极管:稳压 二极管 | SMT
8 | 1 | DSK34 | D5 | SOD-123FL_ L2.7-W1.8-L S3.8-RD | | DSK34 | R+O(宏嘉诚) | C7502709 | LCSC | 二极管:肖特 基二极管 | SMT
9 | 1 | HDR-M_2.54 _1x3P | H8 | HDR-TH_3P-P2.54-V-M | | | | C2937625 | | 连接器:排针 | SMT
10 | 1 | HDR-M_2.54 _1x4P | H9 | HDR-TH_4P-P2.54-V-M | | | | C492403 | | 连接器:排针 | SMT
11 | 1 | LED_0603-R | LED2 | LED_0603 | | | | | | | SMT
12 | 1 | LED_0603-G | LED4 | LED_0603 | | | | | | | SMT
13 | 5 | PAD | P1,P2,P3,P4,P5 | SMD_BD4.0-L4.0-W4.0-D 1.0 | | PAD | | C990001727 1 | LCSC | | SMT
14 | 6 | TPN2R703N L,L1Q(ES) | Q1,Q2,Q3,Q4,Q5,Q6 | PDFN3333-8 _L3.1-W3.2-P0.65-LS3.4-BL_1 | | TPN2R703N L,L1Q(ES) | ElecSuper(静 芯) | C49108772 | LCSC | 三极管/MOS 管/晶体管:场 效应管(MOS FET) | SMT
15 | 2 | 100R | R1,R41 | R0603 | 100R | | | | | 电阻:贴片电 阻 | SMT
16 | 6 | 4.7R | R2,R3,R4,R5,R6,R7 | R0603 | 4.7R | | | | | 电阻:贴片电 阻 | SMT
17 | 3 | 5.1K | R14,R16,R18 | R0603 | 5.1K | | | | | 电阻:贴片电 阻 | SMT
18 | 7 | 1K | R15,R17,R19,R20,R21,R22 ,R54 | R0603 | 1K | | | | | 电阻:贴片电 阻 | SMT
19 | 2 | 10K | R42,R44 | R0603 | 10K | | | | | 电阻:贴片电 阻 | SMT
20 | 1 | 47K | R43 | R0603 | 47K | | | | | 电阻:贴片电 阻 | SMT
21 | 1 | 4.7K | R55 | R0603 | 4.7K | | | | | 电阻:贴片电 阻 | SMT
22 | 1 | SE8650X2-H F | U11 | SOT-23-3_L2 .9-W1.6-P1.9 0-LS2.8-BR | | SE8650X2-H F | SEAWARD( 思旺) | C496615 | LCSC | 电源管理:线 性稳压器(LD O) | SMT

23 | 1 | FD6288Q | U12 | QFN-24_L4.0 -W4.0-P0.50-BL-EP2.6 | FD6288Q | Fortior Tech(峰岹 ) | C328453 | LCSC | 电机驱动芯片 :栅极驱动芯 片 | SMT
24 | 1 | AI8051U-34K 64-QFN48 | U13 | VQFN-48_L6 .0-W6.0-P0.4 0-TL-EP4.1 | AI8051U-34K 64-QFN48 | STC | C42388166 | LCSC | 单片机 /微控 制器 :单片机 ( MCU/MPU/S OC) | SMT

Device | Name
CAP_0805 | 22uF
CAP_0805 | 4.7uf
CAP_0402 | 100nF
CAP_0603 | 10uF
CAP_0603 | 22uF
B5819WS_C 7420331 | B5819WS
BZT52C15_ C19077412 | BZT52C15
DSK34_C75 02709 | DSK34

HDR-M_2.54 _1x3P

HDR-M_2.54 _1x4P

LED_0603-R
LED_0603-G
PAD | PAD
TPN2R703N L,L1Q(ES) | TPN2R703N L,L1Q(ES)
Res_0603 | 100R
Res_0603 | 4.7R
Res_0603 | 5.1K
Res_0603 | 1K
Res_0603 | 10K
Res_0603 | 47K
Res_0603 | 4.7K
SE8650X2-H F | SE8650X2-H F
FD6288Q | FD6288Q
AI8051U-34K 64-QFN48 | AI8051U-34K 64-QFN48

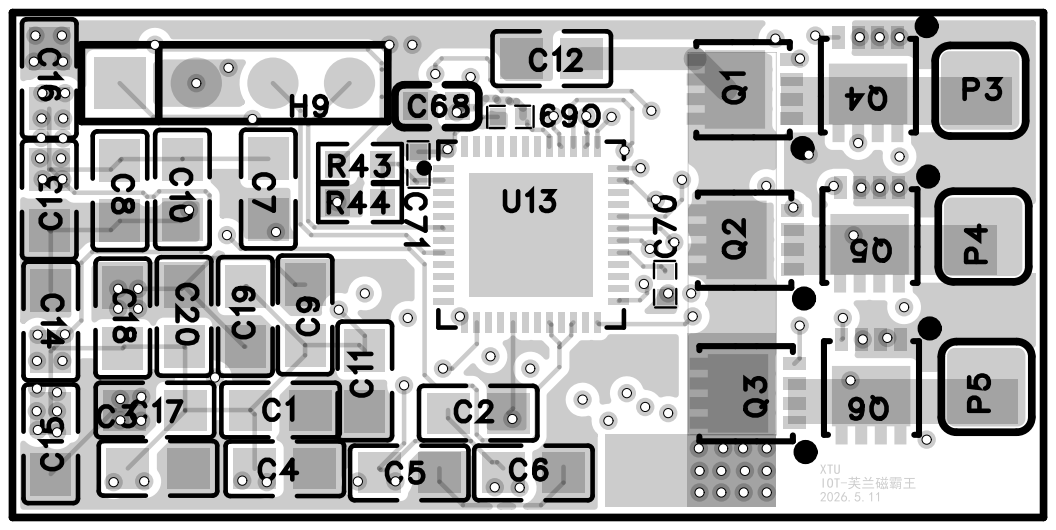
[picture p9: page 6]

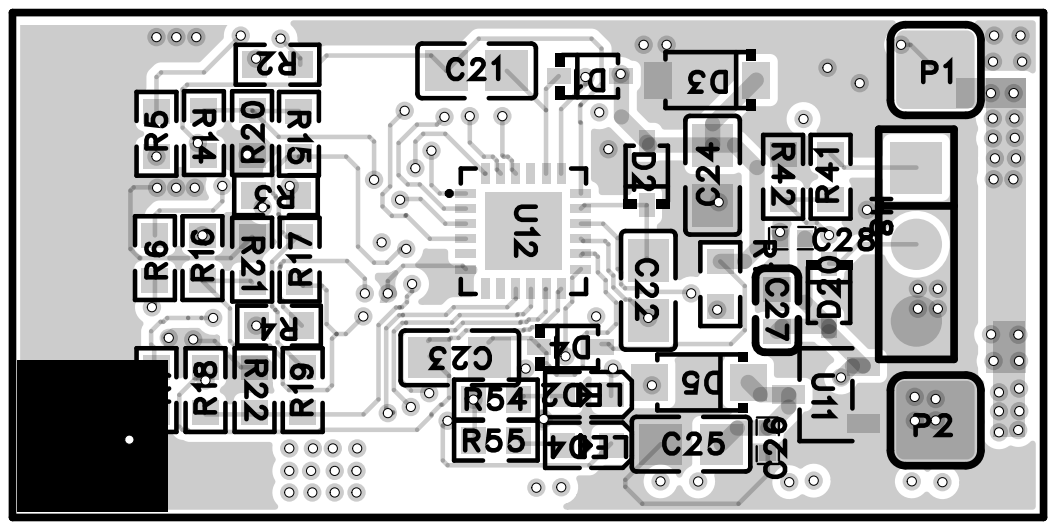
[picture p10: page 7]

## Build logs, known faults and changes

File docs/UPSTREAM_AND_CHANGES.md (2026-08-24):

# 来源与整理记录

## 整理来源

- 本地工作副本：`STC32G144K246_100Pin_Library-master`
- 工作副本远端：<https://github.com/Hongshiits/iot-furan-STC32G144K246_100Pin_Library>
- 整理基准分支：`main`
- 整理基准提交：`cc3cec59f05caa365820f97e2efc7dc2046953d1`
- 主要工程：`Example/Coreboard_Demo/E05_pwm_demo`

新仓库的固件部分采用源码快照，不复制旧库中与 E05 无关的大量示例和软件安装包。上面的提交哈希用于追溯固件整理时的来源状态；后来加入的上级目录硬件与机械资料使用独立导入清单追溯。

## 基准提交之后的工作区修改

整理时，以下 21 个受版本控制的源文件相对基准提交存在未提交修改；新仓库收录的是这些文件的当前工作区版本。

应用层（18 个）：

- `firmware/E05_pwm_demo/user/adc.c`
- `firmware/E05_pwm_demo/user/adc.h`
- `firmware/E05_pwm_demo/user/algorithm.c`
- `firmware/E05_pwm_demo/user/eeprom.c`
- `firmware/E05_pwm_demo/user/eeprom.h`
- `firmware/E05_pwm_demo/user/encoder.c`
- `firmware/E05_pwm_demo/user/fsm_leg.c`
- `firmware/E05_pwm_demo/user/fsm_leg.h`
- `firmware/E05_pwm_demo/user/gpio.c`
- `firmware/E05_pwm_demo/user/hornshell.c`
- `firmware/E05_pwm_demo/user/imu.c`
- `firmware/E05_pwm_demo/user/isr_leg.c`
- `firmware/E05_pwm_demo/user/isr_leg.h`
- `firmware/E05_pwm_demo/user/main.c`
- `firmware/E05_pwm_demo/user/pit.c`
- `firmware/E05_pwm_demo/user/pt_headfile.c`
- `firmware/E05_pwm_demo/user/pwm.c`
- `firmware/E05_pwm_demo/user/pwm.h`

库层（3 个）：

- `firmware/libraries/zf_common/zf_common_function.c`
- `firmware/libraries/zf_common/zf_common_function.h`
- `firmware/libraries/zf_device/zf_device_imu660ra.c`

相对基准提交，这组修改合计约 `860` 行新增、`319` 行删除。基准提交本身也已经包含 Furandoru 项目的早期定制历史，因此不能将其视为逐飞官方原版。

## 整理规则

保留：

- `E05_pwm_demo/user` 中的实际应用源码
- Keil 工程文件及工程直接引用的 `Coreboard_Demo/libraries`
- 工程要求的二进制 `.LIB` 组件
- `tools/e05_pwm_virtual_env` 中的 PC 仿真脚本
- 上级工作目录中通过公开安全审计的 EDA 导出、制造文件和 3D/机械模型
- GPLv3 许可证和原文件中的版权声明

移除：

- `mdk/out_file` 编译产物、列表、日志和中间文件
- `.venv`、`__pycache__` 和仿真生成的 CSV
- `.uvgui.*`、`.uvopt*`、Keil Assistant 日志等个人状态
- 与 E05 无关的示例和上位机软件
- E05 根目录下未被工程引用且早于 `user/` 版本的 `main.c`、`fsm_leg.c` 备份
- 含本地凭据的 `.eprj*`、含 Keil 许可证码的构建日志/聚合包、锁文件和超大扫描参考图

## 许可证与署名

逐飞库源文件声明其按 GPLv3（或后续版本）授权，并要求保留成都逐飞科技有限公司的版权声明。本仓库保留相关源文件头和根目录 `LICENSE`；后续修改也应继续遵守兼容的 GPL 条款。

工程还包含授权尚未在源目录中明确的 Keil/STC 文件、两个预编译 `.LIB` 以及部分硬件/机械资产。这些文件为保持当前工程与维护者指定的公开快照而保留，但公开可见不等于授权已统一确认；具体路径和处理建议见根目录 `THIRD_PARTY_NOTICES.md`。

## 2026-08-24 硬件与机械资料导入

导入来源为同一项目上级目录的 `hw/` 与 `model/`。共盘点 320 个源文件；每个文件的原路径、修改时间、源 SHA-256、发布路径、发布 SHA-256、去重和排除原因均记录在 `docs/ASSET_IMPORT_MAP.csv`，统计摘要见 `docs/ASSET_IMPORT_SUMMARY.md`。

同名不同内容的独立工程/导出使用 `__YYYYMMDD-HHMMSS` 后缀；字节完全相同的副本通常只保留一份。N30 主板支架 DXF 是唯一跨上下文例外，以同时保持硬件接口入口和完整第三方快照。SolidWorks 装配体和其依赖零件不直接改名，并保持同目录。公开安全审计发现原始立创 EDA 本地数据库含凭据字段、MUX 构建日志含 Keil 许可证码，因此这些原件和夹带它们的聚合包未发布。

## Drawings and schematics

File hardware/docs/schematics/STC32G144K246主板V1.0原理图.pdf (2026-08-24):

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
STC32G144K246主板 | 硫酸铜
| V1.0.3.0
2026/1/5 | 11:38:58
Title: | Author:

Date:

Revision:
Size: A4 | Time: | Sheet: | of:

### Subtitle: Revision

V1.0 | 初始版本。
版本号 | 修订日期 | 修订记录

2025-12-19

在此文件中，仅以版本号前两位(发行版)，划分版本之间的区别。

版权所有，保留一切权利。
本公司致力于产品的不断改善和功能升级，内容如有改动，恕不另行通知。

# SEEKFREE

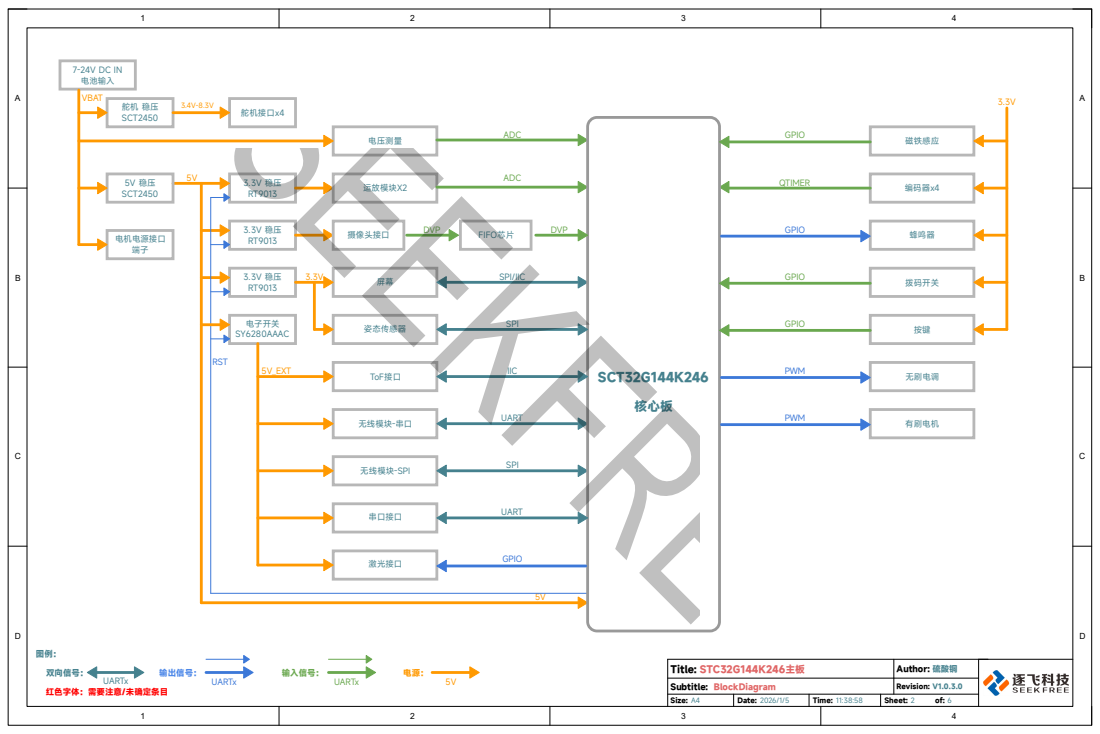
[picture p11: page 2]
STC32G144K246主板; 硫酸铜; Title:; Author:; Revision:; Subtitle: BlockDiagram; 双向信号：; 输出信号：; 输入信号：; 红色字体：需要注意/未确定条目; UARTx; 5V 稳压 SCT2450; VBAT; 电池输入; 舵机 稳压 SCT2450; 电机电源接口 端子; 舵机接口x4; 姿态传感器; 编码器x4; 无线模块-串口; 激光接口; DVP; SPI/IIC; QTIMER; 电子开关 SY6280AAAC; RST; 运放模块X2; ADC; 摄像头接口; 无线模块-SPI; UART; SPI; 电压测量; SCT32G144K246; 磁铁感应 GPIO; ToF接口 5V_EXT; IIC; 有刷电机; 无刷电调; 蜂鸣器; 拨码开关 GPIO; 按键 GPIO; PWM; GPIO; 核心板; FIFO芯片; 串口接口; SEEKFREE

# Subtitle: MCU GND

无线 模块 串口 | Tx Rx CMD | 9.3 9.2 9.4 5.4

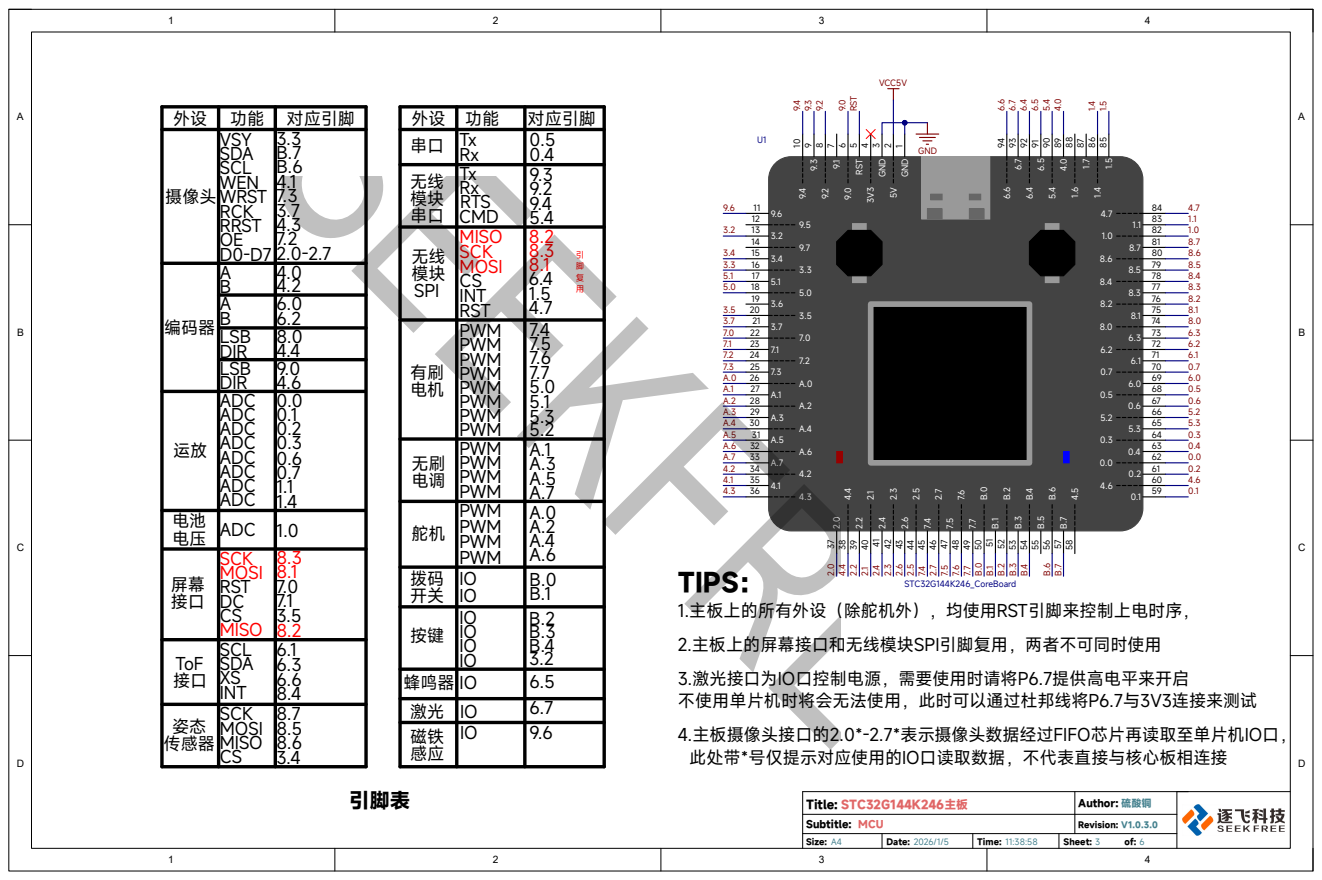
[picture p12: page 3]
STC32G144K246主板; 硫酸铜; Title:; Author:; Revision:; 60 GND; 3 3V3 4 RST; STC32G144K246_CoreBoard; 对应引脚; 摄像头; VSY SCL; SDA; 引脚表; GND; VCC5V 9.49.3 9.2; 9.0RST; WEN; WRST; RCK RRST OE; RTS; SEEKFREE

无线 模块 SPI | MISO SCK MOSI CS INT RST | 8.3 引 8.1 脚 6.4 复 1.5 用 4.7

编码器 | A B | 4.0 4.2
A B | 6.0 6.2
LSB DIR | 8.0 4.4
LSB DIR | 9.0 4.6
运放 | ADC ADC ADC ADC | 0.0 0.1 0.2 0.3 0.6 0.7 1.1 1.4

有刷 电机 | PWM PWM PWM PWM | 7.4 7.5 7.6 7.7 5.0 5.1 5.2

无刷 电调 | PWM PWM | A.1 A.3 A.5 A.7

舵机 | PWM PWM | A.0 A.2 A.4 A.6

电压 | ADC 电池 | 1.0
屏幕 接口 | SCK MOSI RST DC CS MISO | 8.3 8.1 7.0 7.1 3.5 8.2

拨码 开关 | IO IO | B.0 B.1
按键 | IO IO | B.2 B.3 B.4 3.2

TIPS：
1.主板上的所有外设（除舵机外），均使用RST引脚来控制上电时序，
2.主板上的屏幕接口和无线模块SPI引脚复用，两者不可同时使用
3.激光接口为IO口控制电源，需要使用时请将P6.7提供高电平来开启
不使用单片机时将会无法使用，此时可以通过杜邦线将P6.7与3V3连接来测试
4.主板摄像头接口的2.0*-2.7*表示摄像头数据经过FIFO芯片再读取至单片机IO口，
此处带*号仅提示对应使用的IO口读取数据，不代表直接与核心板相连接

ToF 接口 | SCL SDA XS INT | 6.1 6.3 6.6 8.4

蜂鸣器 IO | | 6.5
激光 | IO | 6.7
磁铁 感应 | IO | 9.6

姿态 传感器 | SCK MOSI MISO CS | 8.7 8.5 8.6 3.4

# 5V外设电源控制

电源接口/开关 | 电机电源接口

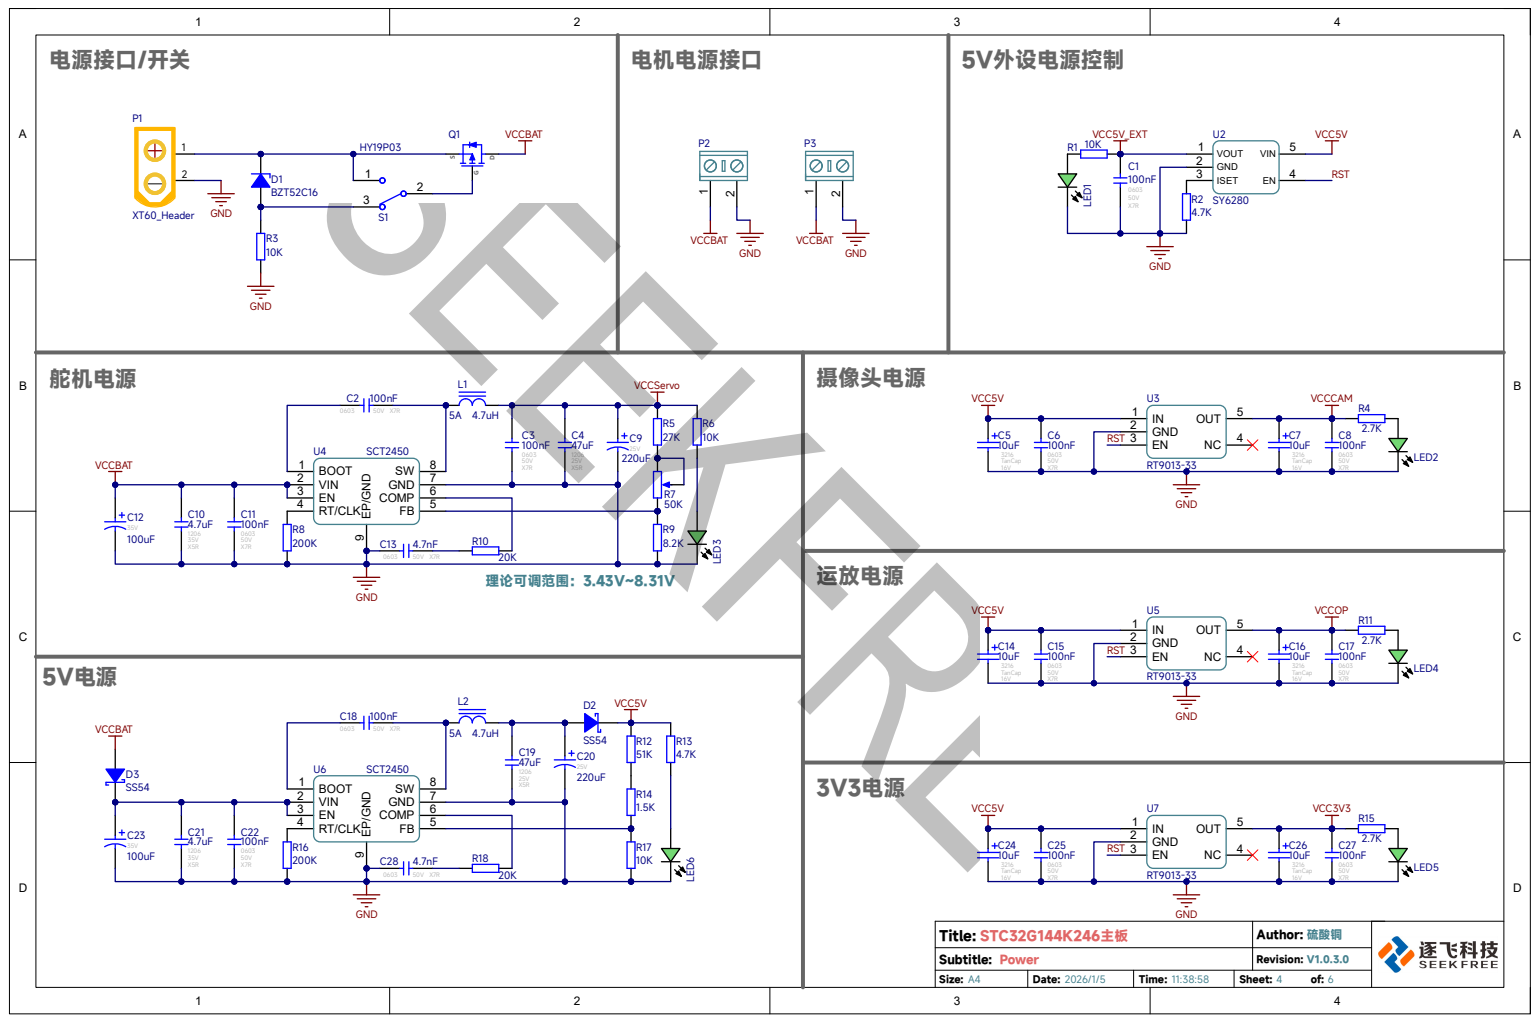
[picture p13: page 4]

# 屏幕接口 串口接口

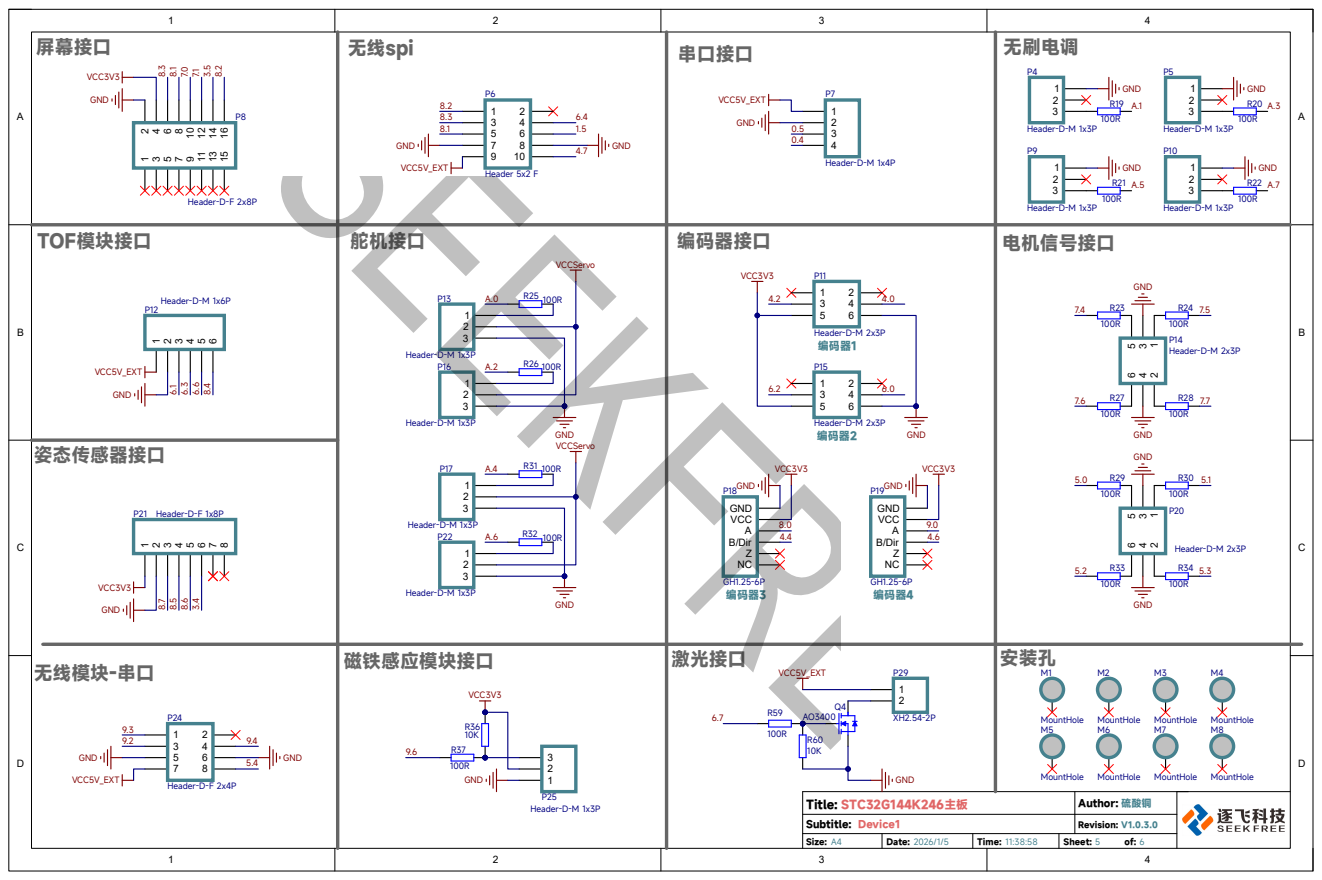
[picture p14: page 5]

# 摄像头接口

## 这是运放模块接口

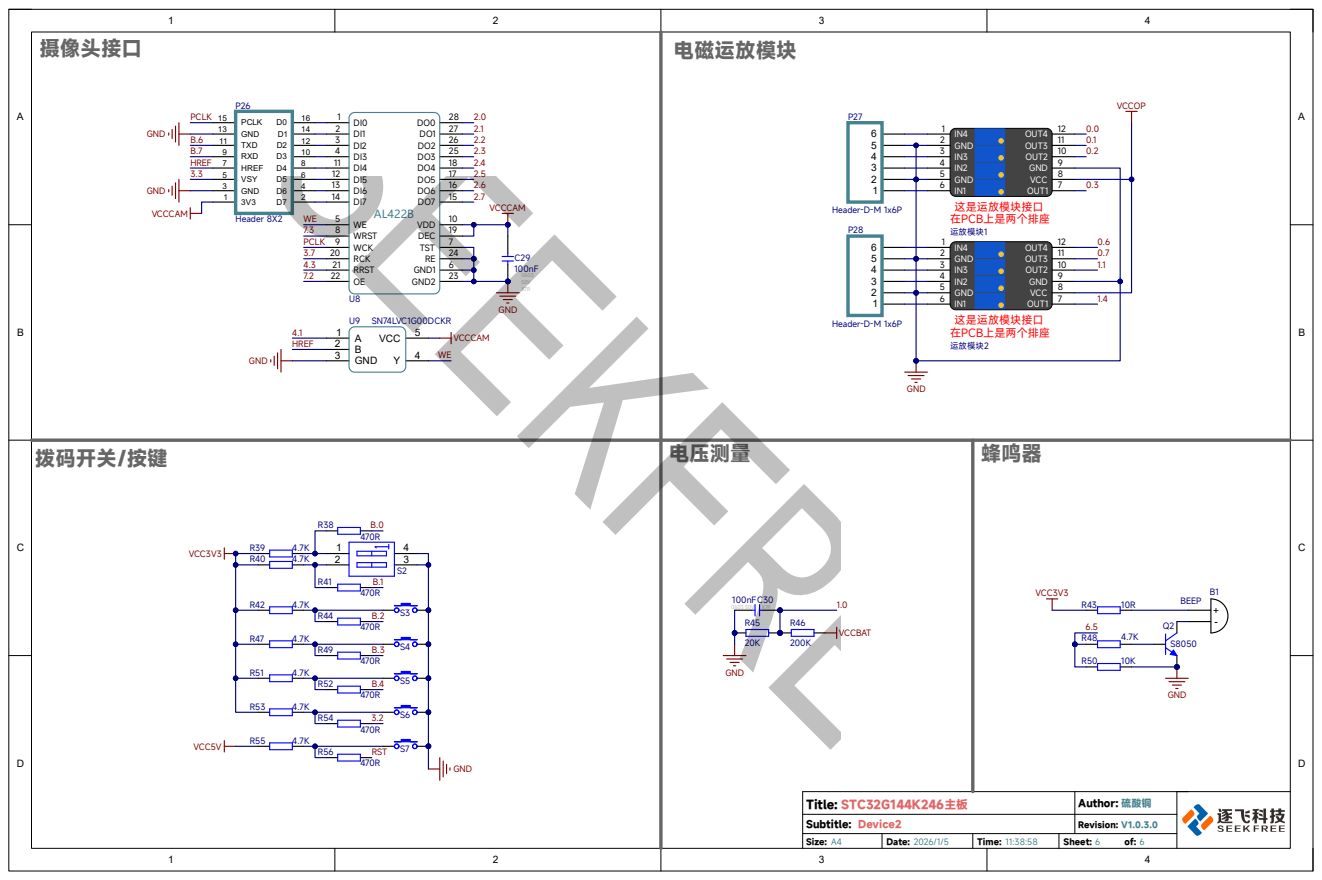
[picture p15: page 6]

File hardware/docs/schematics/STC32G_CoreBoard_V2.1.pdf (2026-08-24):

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
STC32G_CoreBoard | 路飞
| V2.1.0.0
2024/11/22 | 11:32:02
Title: | Author:

Date:

Revision:
Size: A4 | Time: | Sheet: | of:

### Subtitle: Revision

V1.0.0.0 | 初始版本。
版本号 | 修订日期 | 修订记录

2022-03-08

在此文件中，仅以版本号前两位(发行版)，划分版本之间的区别。

版权所有，保留一切权利。
本公司致力于产品的不断改善和功能升级，内容如有改动，恕不另行通知。
V2.0.0.0 | 2023-12-23 | 单片机供电改为3.3V。 修改复位电路。
V2.1.0.0 | 2024-10-23 | 修改USB-TTL芯片。

# 2.3 ².7 2.6 2.5 2.4 3.2 3.3 3.4

单片机 | 下载接口

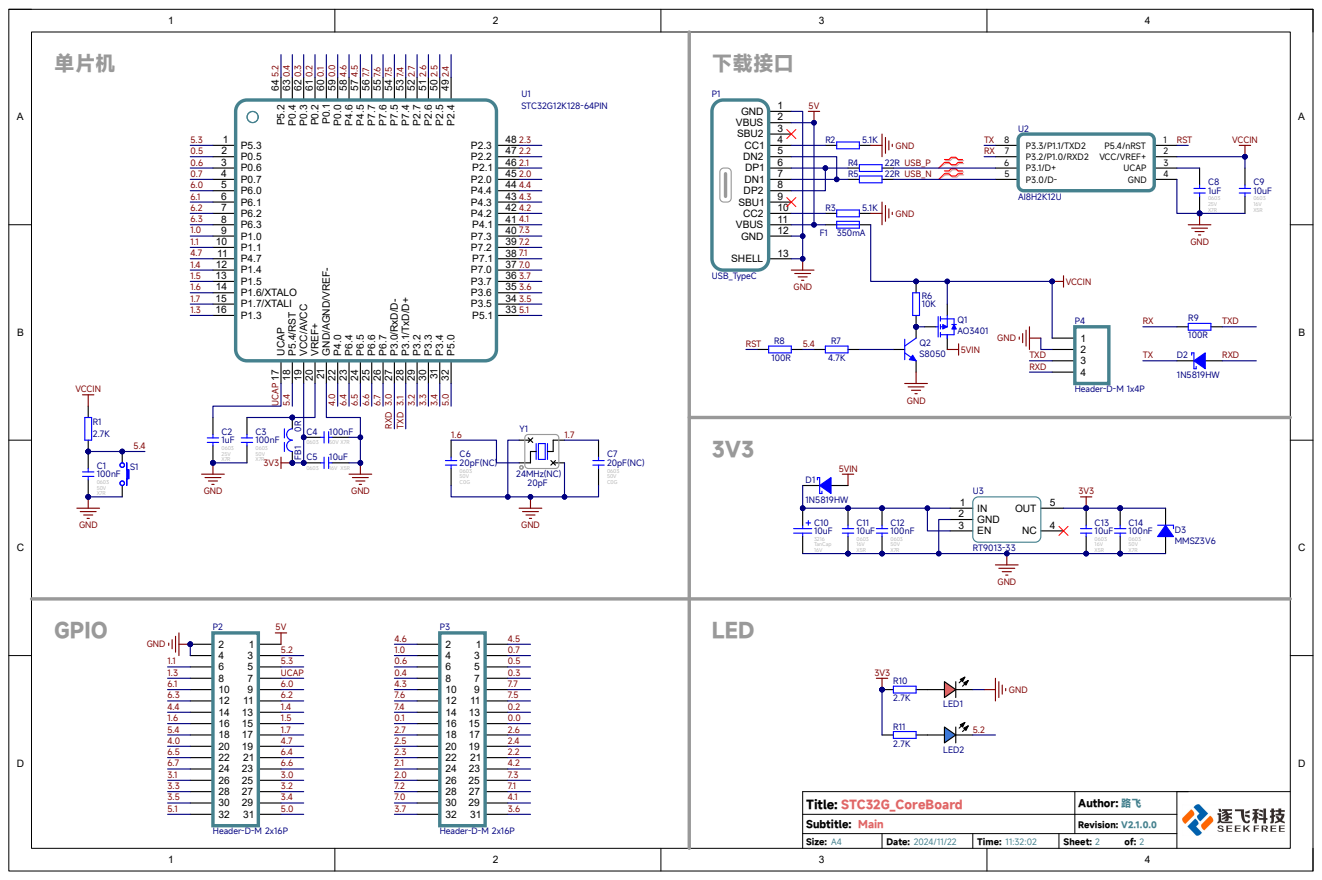
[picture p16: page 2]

Subtitle: Main UCAP 17 P⁵.4/RST 18 VCC/AVCC 19 VREF+ 20 GND/AGND/VREF⁻ 21 P⁴.0 22 P⁶.4 23 P⁶.5 24 P⁶.6 25 P⁶.7 26 P³.0/RxD/D⁻ 27 P³.1/TxD/D⁺ 28 P³.2 29 P³.3 30 P³.4 31 P⁵.0 32

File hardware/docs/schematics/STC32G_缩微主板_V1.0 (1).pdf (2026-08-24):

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
STC32G_缩微主板 | 路飞
| V1.0.2.0
2025/12/10 | 11:14:07
Title: | Author:

Date:

Revision:
Size: A4 | Time: | Sheet: | of:

### Subtitle: Revision

版本号 | 修订日期 | 修订记录

在此文件中，仅以版本号前两位(发行版)，划分版本之间的区别。

版权所有，保留一切权利。
本公司致力于产品的不断改善和功能升级，内容如有改动，恕不另行通知。
V1.0.0.0 | 2025-11-13 | 初始版本。
V1.0.1.0 | 2025-11-19 | 负压电机控制信号接下拉电阻，续流二极管改为SS54。
V1.0.2.0 | 2025-11-25 | 编码器接口添加两个信号引脚，可用于控制STC-FOC驱动

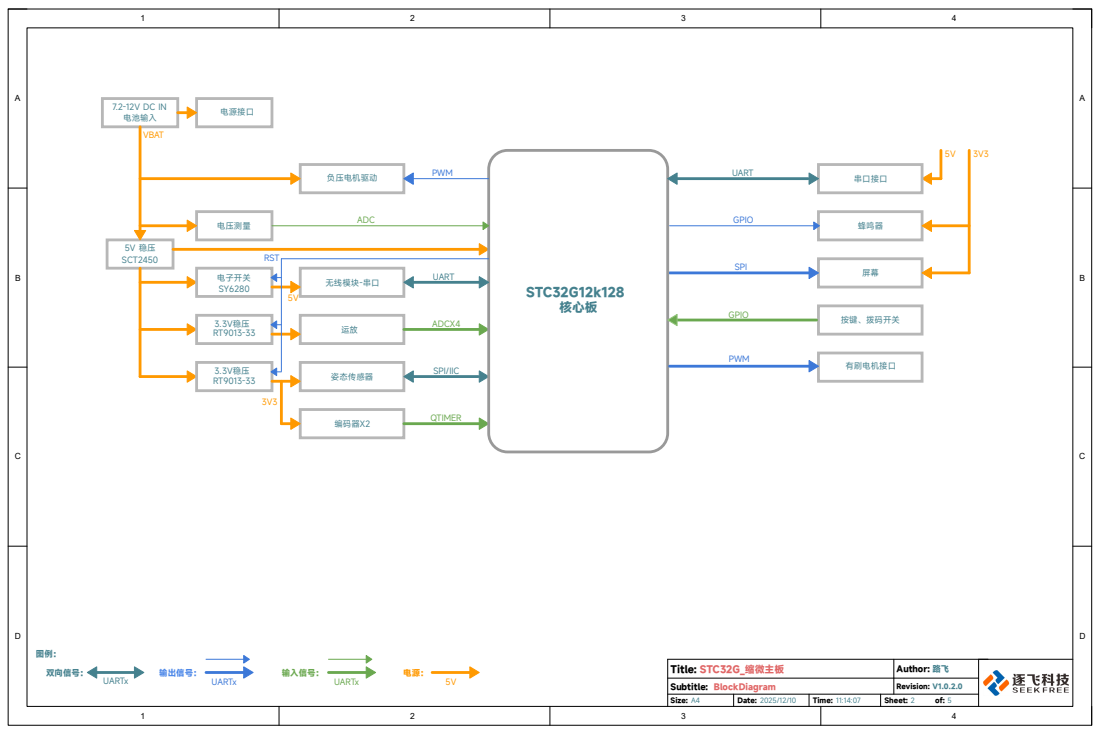
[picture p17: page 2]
STC32G_缩微主板; Title:; Author:; Revision:; Subtitle: BlockDiagram; 双向信号：; 输出信号：; 输入信号：; UARTx; VBAT; 电池输入; 电源接口; 姿态传感器; 编码器X2; 无线模块-串口; SPI/IIC; QTIMER; SPI; SCT2450; STC32G12k128; ADCX4; UART; 电压测量; ADC; 负压电机驱动; 有刷电机接口 PWM; 按键、拨码开关; 蜂鸣器 GPIO; 核心板; 串口接口 PWM; 3.3V稳压; 电子开关; 3.3V稳压 RT9013-33; RST; GPIO

0.1 | 49 0.0 50 7.4 | 51 0.2 52 7.6 | 53 7.5 54 4.3 | 55 7.7 56 0.4 | 57 0.3 58 0.6 | 59 0.5 60 1.0 | 61 0.7 62

# MOSI

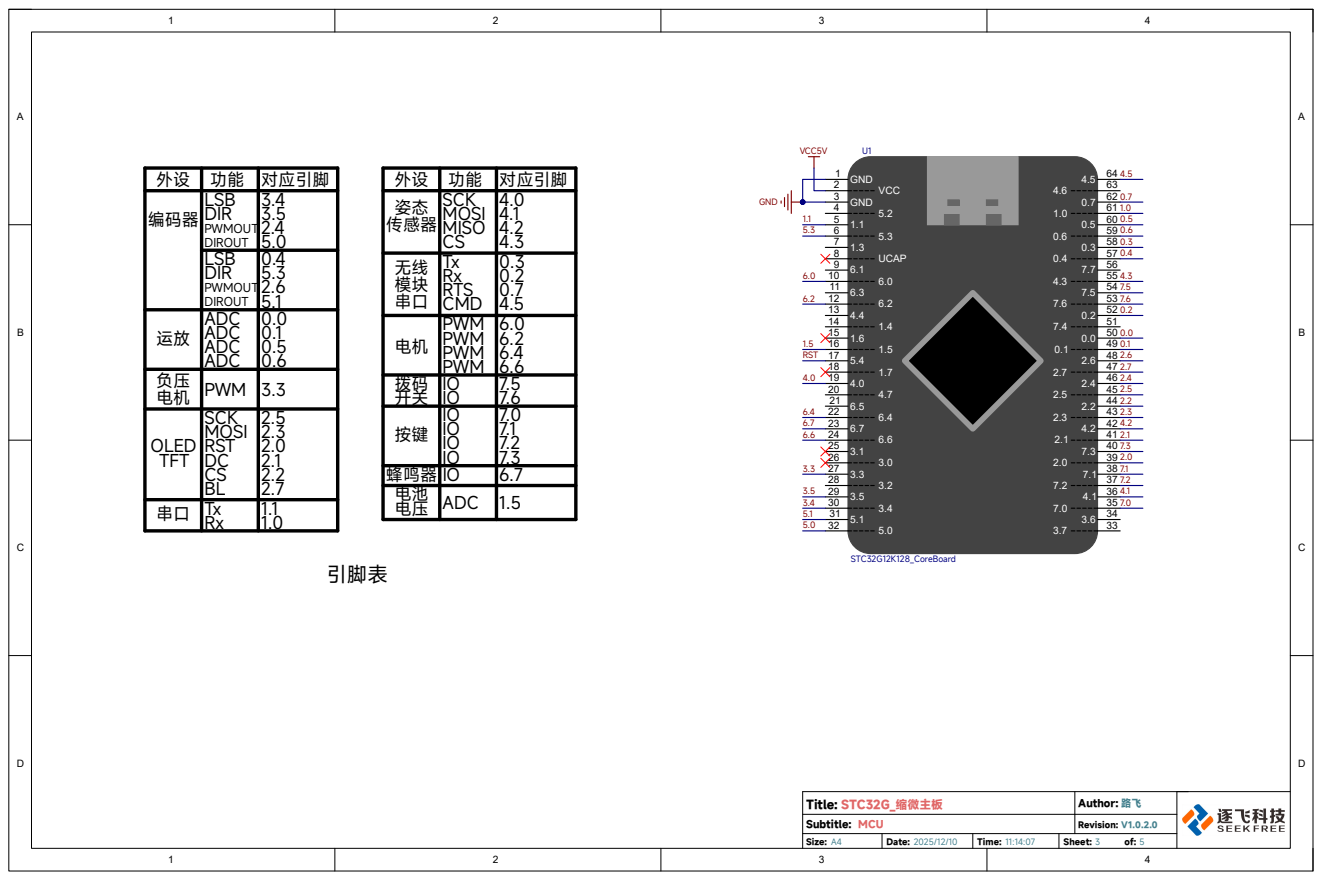
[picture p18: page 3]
STC32G_缩微主板; Title:; Author:; Revision:; Subtitle: MCU; GND 1 VCC 2 GND 3 5.2 4 1.1 5 5.3 6 1.3 7 UCAP 8 6.1 9 6.0 10 6.3 11 6.2 12 4.4 13 1.4 14 1.6 15 1.5 16 5.4 17 1.7 18 4.0 19 4.7 20 6.5 21 6.4 22 6.7 23 6.6 24; STC32G12K128_CoreBoard; OLED TFT; SCK MOSI RST DC CS BL; MISO CS; Tx Rx RTS; 对应引脚; SCK; 引脚表; 编码器; LSB; DIR; LSB DIR; 电池电压; ADC; GND; VCC5V; RST; 蜂鸣器 IO; CMD; 姿态 传感器; PWMOUT DIROUT

运放 | ADC ADC | 0.0 0.1 0.5 0.6

电机 | PWM PWM | 6.0 6.2 6.4 6.6

负压 电机 | PWM | 3.3

# 电源接口/开关

3V3

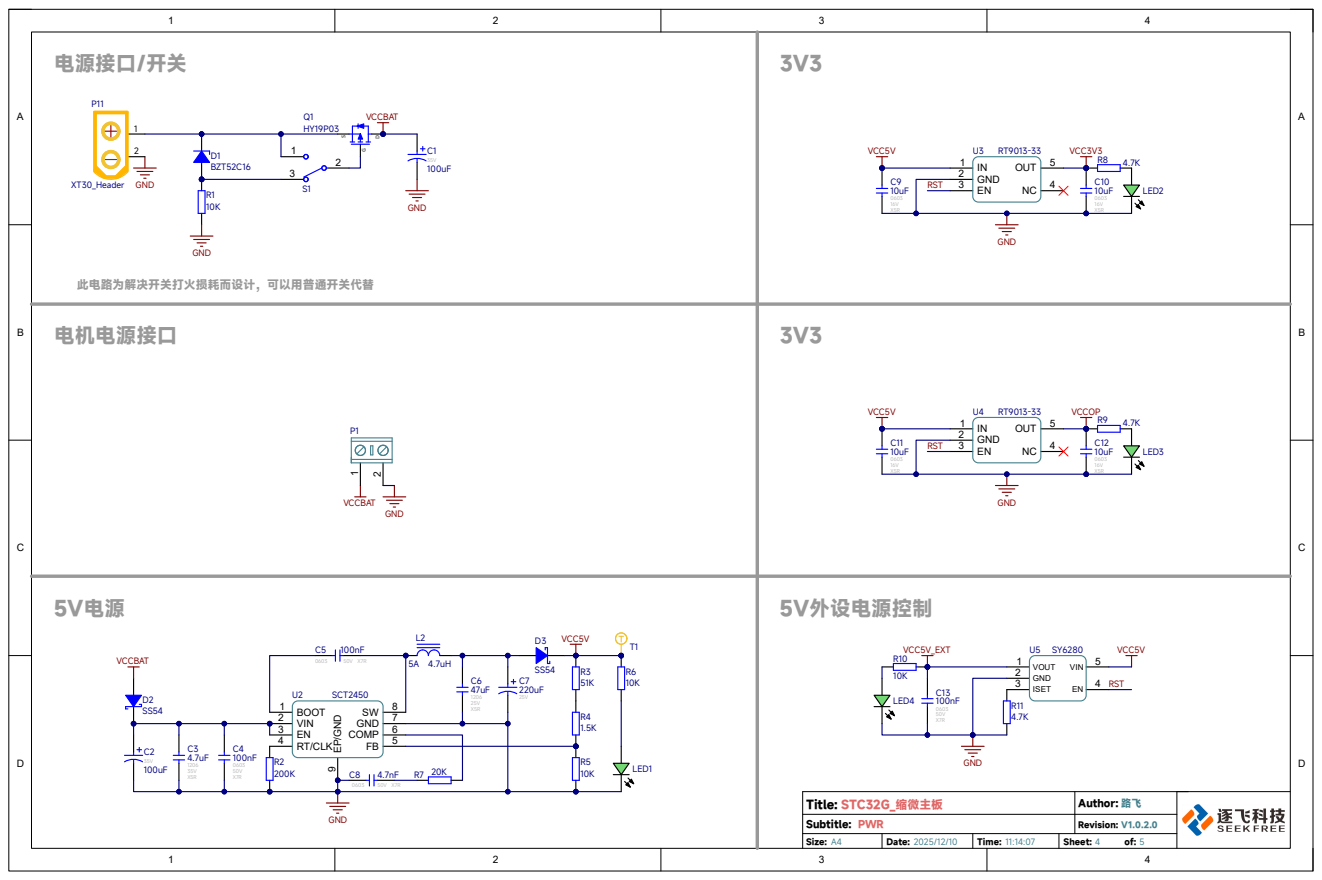
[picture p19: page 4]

# 电磁运放模块接口

# 屏幕接口

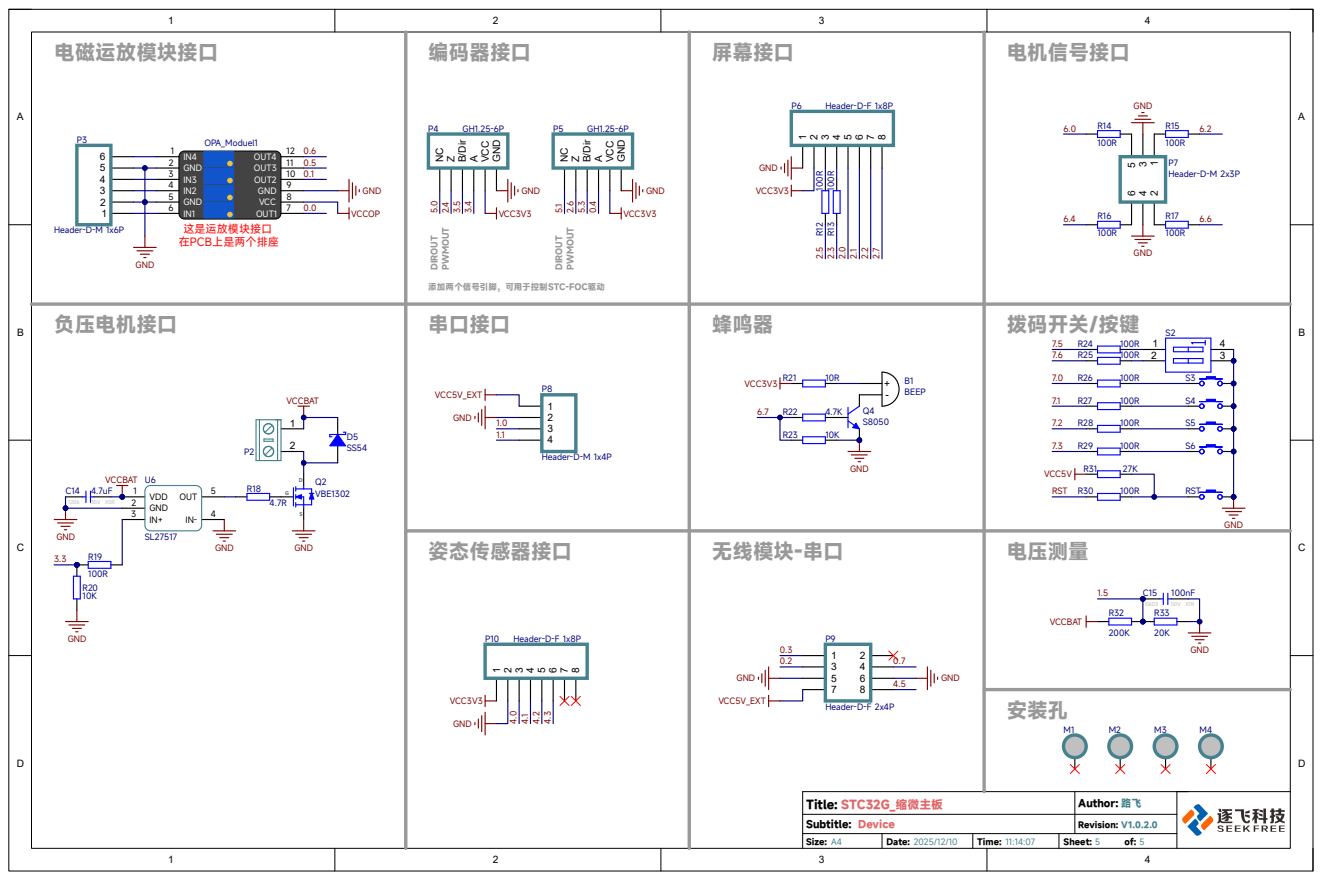
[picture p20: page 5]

ZB/Dir AVCC GND

添加两个信号引脚，可用于控制STC-FOC驱动 DIROUT PWMOUT

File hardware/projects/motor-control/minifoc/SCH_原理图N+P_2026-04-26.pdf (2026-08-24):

# MCU部分

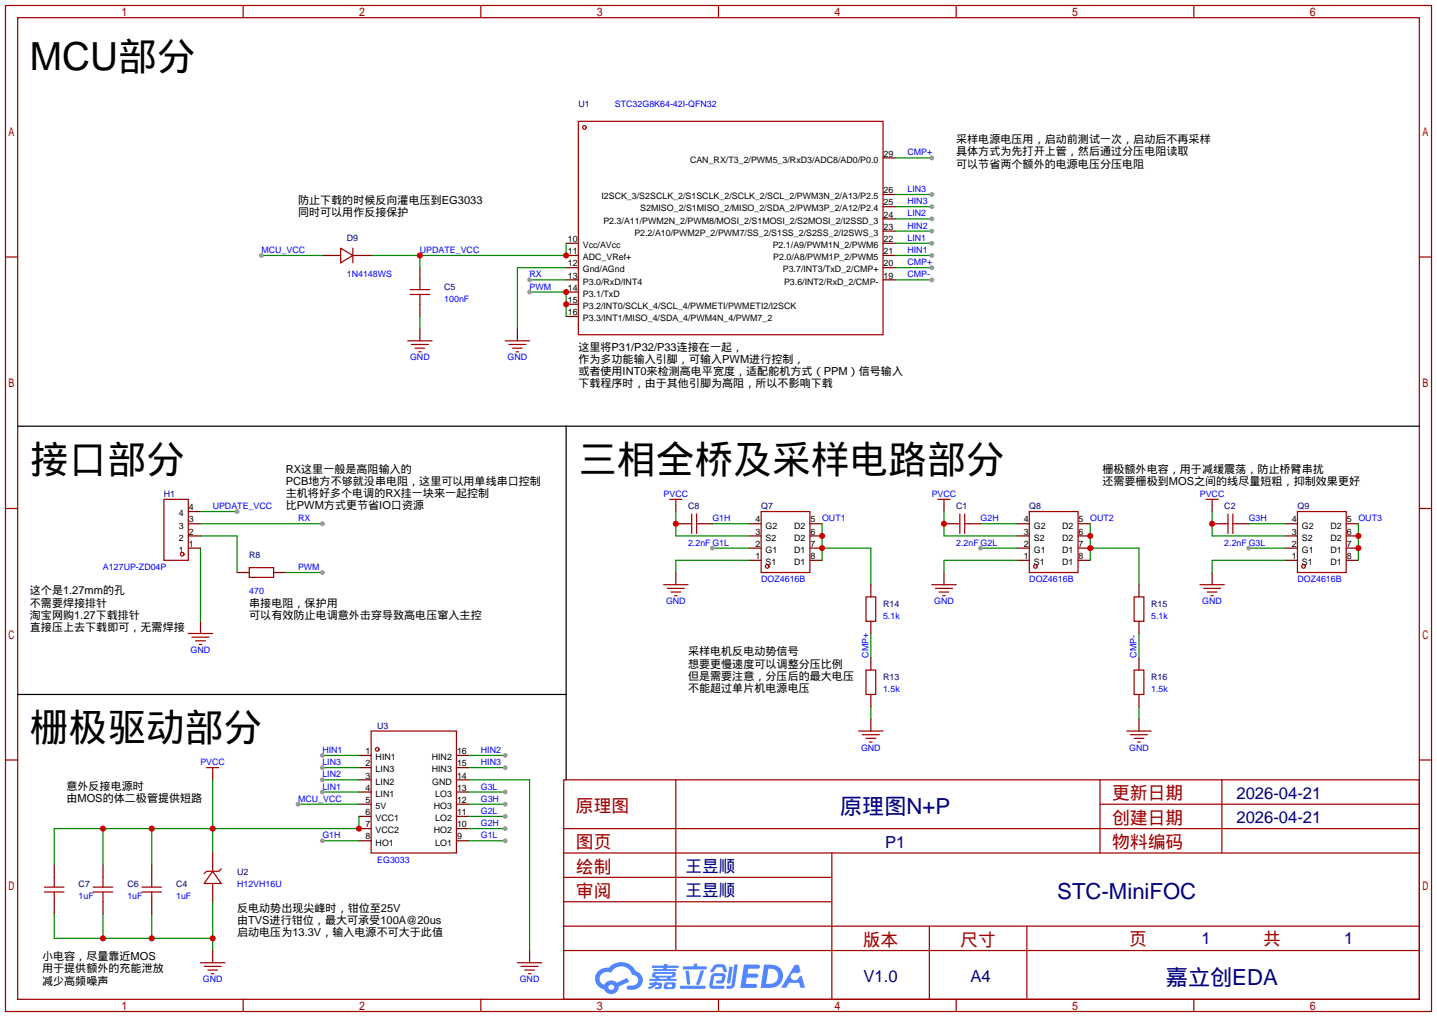
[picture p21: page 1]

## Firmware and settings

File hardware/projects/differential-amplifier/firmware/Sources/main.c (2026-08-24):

//<<AICUBE_USER_HEADER_REMARK_BEGIN>>
////////////////////////////////////////
// 在此添加用户文件头说明信息  
// 文件名称: main.c
// 文件描述: 
// 文件版本: V1.0
// 修改记录:
//   1. (2026-05-06) 创建文件
////////////////////////////////////////
//<<AICUBE_USER_HEADER_REMARK_END>>


#include "config.h"                     //默认已包含stdio.h、intrins.h等头文件


//<<AICUBE_USER_INCLUDE_BEGIN>>
// 在此添加用户头文件包含  
//<<AICUBE_USER_INCLUDE_END>>


//<<AICUBE_USER_GLOBAL_DEFINE_BEGIN>>
// 在此添加用户全局变量定义、用户宏定义以及函数声明  
#define OE1 P33 //使能1，2通道
#define MUX1 P32//切换1，2通道

#define OE2 P36//使能3，4通道
#define MUX2 P34//切换3，4通道

#define ROE P10 //电阻档位使能
#define RMUX P37 //电阻档位选择

#define ADC_RST P17 //采样保持电容清空

void R_GAIN(unsigned char gain);//档位切换，0对应5x，1对应20x，2对应50x
void MUX_CH(unsigned char ch);//选择通道，0~3对应外部的in0~in3

unsigned int ch_val[4] = {0};//用于存储四个通道的数据
//<<AICUBE_USER_GLOBAL_DEFINE_END>>



////////////////////////////////////////
// 项目主函数
// 入口参数: 无
// 函数返回: 无
////////////////////////////////////////
void main(void)
{
    //<<AICUBE_USER_MAIN_INITIAL_BEGIN>>
    // 在此添加用户主函数初始化代码  
    //<<AICUBE_USER_MAIN_INITIAL_END>>

    SYS_Init();

    //<<AICUBE_USER_MAIN_CODE_BEGIN>>
    // 在此添加主函数中运行一次的用户代码  
		R_GAIN(1);//这里可以调节放大倍率
		MUX_CH(0);
    //<<AICUBE_USER_MAIN_CODE_END>>

    while (1)
    {
        //<<AICUBE_USER_MAIN_LOOP_BEGIN>>
        // 在此添加主函数中用户主循环代码
				MUX_CH(0);
				ADC_RST = 0;
				delay_us(10);//清空电荷
				ADC_RST = 1;//恢复高阻状态
				delay_us(75);//等待1.5个周期，峰值保持电路充电
				ch_val[0] = ADC_Convert(3);
			
				
				MUX_CH(1);
				ADC_RST = 0;
				delay_us(10);//清空电荷
				ADC_RST = 1;//恢复高阻状态
				delay_us(75);//等待1.5个周期，峰值保持电路充电
				ch_val[1] = ADC_Convert(3);
			
				
				MUX_CH(2);
				ADC_RST = 0;
				delay_us(10);//清空电荷
				ADC_RST = 1;//恢复高阻状态
				delay_us(75);//等待1.5个周期，峰值保持电路充电
				ch_val[2] = ADC_Convert(3);
			
				
				MUX_CH(3);
				ADC_RST = 0;
				delay_us(10);//清空电荷
				ADC_RST = 1;//恢复高阻状态
				delay_us(75);//等待1.5个周期，峰值保持电路充电
				ch_val[3] = ADC_Convert(3);
				
				
				printf("%u,%u\r\n",ch_val[0],ch_val[1]);//输出
				//delay_ms(1);
        //<<AICUBE_USER_MAIN_LOOP_END>>
    }
}

////////////////////////////////////////
// 系统初始化函数
// 入口参数: 无
// 函数返回: 无
////////////////////////////////////////
void SYS_Init(void)
{
    EnableAccessXFR();                  //使能访问扩展XFR
    IAP_SetTimeBase();                  //设置IAP等待参数,产生1us时基

    //<<AICUBE_USER_PREINITIAL_CODE_BEGIN>>
    // 在此添加用户预初始化代码  
    //<<AICUBE_USER_PREINITIAL_CODE_END>>

    P0M0 = 0x00; P0M1 = 0x00;           //初始化P0口为准双向口模式
    P1M0 = 0x00; P1M1 = 0x00;           //初始化P1口为准双向口模式
    P2M0 = 0x00; P2M1 = 0x00;           //初始化P2口为准双向口模式
    P3M0 = 0x00; P3M1 = 0x00;           //初始化P3口为准双向口模式
    P4M0 = 0x00; P4M1 = 0x00;           //初始化P4口为准双向口模式
    P5M0 = 0x00; P5M1 = 0x00;           //初始化P5口为准双向口模式
    P6M0 = 0x00; P6M1 = 0x00;           //初始化P6口为准双向口模式
    P7M0 = 0x00; P7M1 = 0x00;           //初始化P7口为准双向口模式

    PORT1_Init();                       //P1口初始化
    PORT3_Init();                       //P3口初始化
    CLK_Init();                         //时钟模块初始化
    UART1_Init();                       //串口1初始化
    ADC_Init();                         //ADC初始化

    //<<AICUBE_USER_INITIAL_CODE_BEGIN>>
    // 在此添加用户初始化代码  
    //<<AICUBE_USER_INITIAL_CODE_END>>

    EnableGlobalInt();                  //使能全局中断
}

////////////////////////////////////////
// 微秒延时函数
// 入口参数: us (设置延时的微秒值)
// 函数返回: 无
////////////////////////////////////////
void delay_us(uint16_t us)
{
    do
    {
        NOP(30);                        //(MAIN_Fosc + 500000) / 1000000 - 10
    } while (--us);
}


////////////////////////////////////////
// 毫秒延时函数
// 入口参数: ms (设置延时的毫秒值)
// 函数返回: 无
////////////////////////////////////////
void delay_ms(uint16_t ms)
{
    uint16_t i;

    do
    {
        i = MAIN_Fosc / 10000;
        while (--i);
    } while (--ms);
}


//<<AICUBE_USER_FUNCTION_IMPLEMENT_BEGIN>>
// 在此添加用户函数实现代码  
void R_GAIN(unsigned char gain)//档位切换，0对应5x，1对应20x，2对应50x
{
	if(gain==0){ROE = 1;}
	if(gain==1){ROE = 0;RMUX = 0;}
	if(gain==2){ROE = 0;RMUX = 1;}
}

void MUX_CH(unsigned char ch)//选择通道，0~3对应外部的in0~in3
{
	OE1 = 1; OE2 = 1;
	if(ch == 0){OE1 = 0;OE2 = 1;MUX1 = 0;}
	if(ch == 1){OE1 = 0;OE2 = 1;MUX1 = 1;}
	if(ch == 2){OE1 = 1;OE2 = 0;MUX2 = 0;}
	if(ch == 3){OE1 = 1;OE2 = 0;MUX2 = 1;}
	delay_us(50);//切换通道前等待一个周期，方便信号跟随，否则第一个周期的波形比较烂
}
//<<AICUBE_USER_FUNCTION_IMPLEMENT_END>>

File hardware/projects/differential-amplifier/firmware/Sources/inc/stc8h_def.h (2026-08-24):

#ifndef __STC8H_DEF_H__
#define __STC8H_DEF_H__

/////////////////////////////////////////////////

#include "stc8h.h"
#include "def.h"

/////////////////////////////////////////////////

#define PORT_SetInitLevelLow(p, b)      CLR_REG_BIT(P##p, (b))
#define PORT_SetInitLevelHigh(p, b)     SET_REG_BIT(P##p, (b))

#define PORT_SetQuasiMode(p, b)         CLR_REG_BIT(P##p##M0, (b)); \
                                        CLR_REG_BIT(P##p##M1, (b))

#define PORT_SetPushPullMode(p, b)      SET_REG_BIT(P##p##M0, (b)); \
                                        CLR_REG_BIT(P##p##M1, (b))

#define PORT_SetHighZInputMode(p, b)    CLR_REG_BIT(P##p##M0, (b)); \
                                        SET_REG_BIT(P##p##M1, (b))

#define PORT_SetOpenDrainMode(p, b)     SET_REG_BIT(P##p##M0, (b)); \
                                        SET_REG_BIT(P##p##M1, (b))

#define PORT_EnablePullUp(p, b)         SET_REG_BIT(P##p##PU, (b))
#define PORT_DisablePullUp(p, b)        CLR_REG_BIT(P##p##PU, (b))

#define PORT_EnablePullDown(p, b)       SET_REG_BIT(P##p##PD, (b))
#define PORT_DisablePullDown(p, b)      CLR_REG_BIT(P##p##PD, (b))

#define PORT_EnableSchmitt(p, b)        CLR_REG_BIT(P##p##NCS, (b))
#define PORT_DisableSchmitt(p, b)       SET_REG_BIT(P##p##NCS, (b))

#define PORT_SetSlewRateFast(p, b)      CLR_REG_BIT(P##p##SR, (b))
#define PORT_SetSlewRateNormal(p, b)    SET_REG_BIT(P##p##SR, (b))

#define PORT_SetDrivingStrong(p, b)     CLR_REG_BIT(P##p##DR, (b))
#define PORT_SetDrivingNormal(p, b)     SET_REG_BIT(P##p##DR, (b))

#define PORT_SetAnalogInput(p, b)       CLR_REG_BIT(P##p##IE, (b))
#define PORT_SetDigitalInput(p, b)      SET_REG_BIT(P##p##IE, (b))

#define SetP0nInitLevelLow(b)           PORT_SetInitLevelLow(0, (b))
#define SetP1nInitLevelLow(b)           PORT_SetInitLevelLow(1, (b))
#define SetP2nInitLevelLow(b)           PORT_SetInitLevelLow(2, (b))
#define SetP3nInitLevelLow(b)           PORT_SetInitLevelLow(3, (b))
#define SetP4nInitLevelLow(b)           PORT_SetInitLevelLow(4, (b))
#define SetP5nInitLevelLow(b)           PORT_SetInitLevelLow(5, (b))
#define SetP6nInitLevelLow(b)           PORT_SetInitLevelLow(6, (b))
#define SetP7nInitLevelLow(b)           PORT_SetInitLevelLow(7, (b))

#define SetP0nInitLevelHigh(b)          PORT_SetInitLevelHigh(0, (b))
#define SetP1nInitLevelHigh(b)          PORT_SetInitLevelHigh(1, (b))
#define SetP2nInitLevelHigh(b)          PORT_SetInitLevelHigh(2, (b))
#define SetP3nInitLevelHigh(b)          PORT_SetInitLevelHigh(3, (b))
#define SetP4nInitLevelHigh(b)          PORT_SetInitLevelHigh(4, (b))
#define SetP5nInitLevelHigh(b)          PORT_SetInitLevelHigh(5, (b))
#define SetP6nInitLevelHigh(b)          PORT_SetInitLevelHigh(6, (b))
#define SetP7nInitLevelHigh(b)          PORT_SetInitLevelHigh(7, (b))

#define SetP0nQuasiMode(b)              PORT_SetQuasiMode(0, (b))
#define SetP1nQuasiMode(b)              PORT_SetQuasiMode(1, (b))
#define SetP2nQuasiMode(b)              PORT_SetQuasiMode(2, (b))
#define SetP3nQuasiMode(b)              PORT_SetQuasiMode(3, (b))
#define SetP4nQuasiMode(b)              PORT_SetQuasiMode(4, (b))
#define SetP5nQuasiMode(b)              PORT_SetQuasiMode(5, (b))
#define SetP6nQuasiMode(b)              PORT_SetQuasiMode(6, (b))
#define SetP7nQuasiMode(b)              PORT_SetQuasiMode(7, (b))

#define SetP0nPushPullMode(b)           PORT_SetPushPullMode(0, (b))
#define SetP1nPushPullMode(b)           PORT_SetPushPullMode(1, (b))
#define SetP2nPushPullMode(b)           PORT_SetPushPullMode(2, (b))
#define SetP3nPushPullMode(b)           PORT_SetPushPullMode(3, (b))
#define SetP4nPushPullMode(b)           PORT_SetPushPullMode(4, (b))
#define SetP5nPushPullMode(b)           PORT_SetPushPullMode(5, (b))
#define SetP6nPushPullMode(b)           PORT_SetPushPullMode(6, (b))
#define SetP7nPushPullMode(b)           PORT_SetPushPullMode(7, (b))

#define SetP0nHighZInputMode(b)         PORT_SetHighZInputMode(0, (b))
#define SetP1nHighZInputMode(b)         PORT_SetHighZInputMode(1, (b))
#define SetP2nHighZInputMode(b)         PORT_SetHighZInputMode(2, (b))
#define SetP3nHighZInputMode(b)         PORT_SetHighZInputMode(3, (b))
#define SetP4nHighZInputMode(b)         PORT_SetHighZInputMode(4, (b))
#define SetP5nHighZInputMode(b)         PORT_SetHighZInputMode(5, (b))
#define SetP6nHighZInputMode(b)         PORT_SetHighZInputMode(6, (b))
#define SetP7nHighZInputMode(b)         PORT_SetHighZInputMode(7, (b))
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
